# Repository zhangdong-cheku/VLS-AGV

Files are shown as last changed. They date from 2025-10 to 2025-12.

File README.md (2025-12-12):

# VLS-AGV

<p align="center">
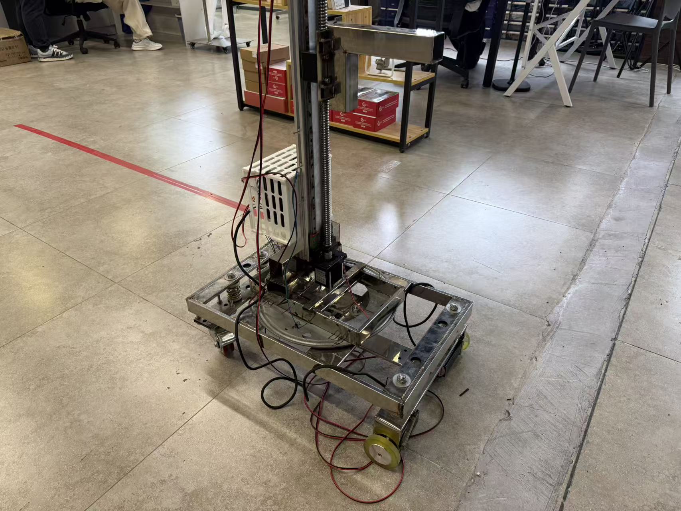
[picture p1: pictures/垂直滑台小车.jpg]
  
  
垂直滑台自主机器人小车 VLS-AGV (Vertical Linear Stage AGV)
针对商用自动导引车(AGV)解决方案成本高的问题，本项目旨在为用户提供一套低成本、可二次开发的开源AGV技术方案。核心亮点是可旋转与可垂直作业组合，支持外接机械臂的开发，在保证性能的同时降低成本，适配中小型仓库物料存取、车间工序转运、实验室样品搬运、零售补货等场景灵活作业。
自主机器人小车由五大核心层级组成：底盘（移动与减震）、底座（承载）、回转支承（左右方向调节）、直线滑动模组（机械臂上下移动调节），机械臂拓展底座（功能延伸接口）。小车的长宽高尺寸为680 mm×412 mm×1121 mm。
其中主动轮为编码器计米轮，由步进电机驱动，从动轮为万向转动轮。底盘与承载底座之间用减震弹簧连接，以提高行驶的稳定性。上部结构和所抓取物体的重量通过空心转盘传递到承载底座。空心转盘由舵机控制，使直线滑动模组能够自由旋转，实现AGV叉车的旋转作业能力。直线滑动模组实现AGV叉车的垂直作业能力。机械臂拓展底座用料为工业铝型材，方便移动组装，此拓展层供用户自主开发，从而满足特定需求。

In response to the problem of high cost of commercial automatic guided vehicle (AGV) solutions, this project aims to provide users with a set of low-cost and redevelopable open-source AGV technical solutions. The core highlight is the combination of rotatable and vertical operation capabilities, supporting the development of external robotic arms. This ensures performance while reducing costs, making it suitable for flexible operations in scenarios such as material storage and retrieval in small and medium-sized warehouses, process transfer in workshops, sample handling in laboratories, and retail replenishment. The autonomous robot trolley is composed of five core levels: the chassis (for movement and shock absorption), the base (for load-bearing), the slewing bearing (for left and right direction adjustment), the linear sliding module (for up and down movement adjustment of the mechanical arm), and the mechanical arm expansion base (for function extension interface). The dimensions of the car's length, width and height are 680 mm×412 mm× 121 mm. Among them, the driving wheel is the encoder metering wheel, driven by a stepping motor, and the driven wheel is a universal rotating wheel. The chassis and the load-bearing base are connected by shock-absorbing springs to enhance the stability during driving. The weight of the superstructure and the grasped object is transferred to the load-bearing base through the hollow turntable. The hollow turntable is controlled by the servo, enabling the linear sliding module to rotate freely and achieving the rotational operation capability of the AGV forklift. The linear sliding module enables the vertical operation capability of AGV forklifts. The material of the mechanical arm expansion base is industrial aluminum profiles, which is convenient for movement and assembly. This expansion layer is available for users to develop independently to meet specific needs.

<p align="center">
  

## 致谢
感谢项目组成员李小峰，田许杰在项目迭代与数据处理中做出的贡献，感谢张东老师在项目方案上的精准指导，也感谢项目组其他成员的通力协作。

## 加入社区

<p align="center">
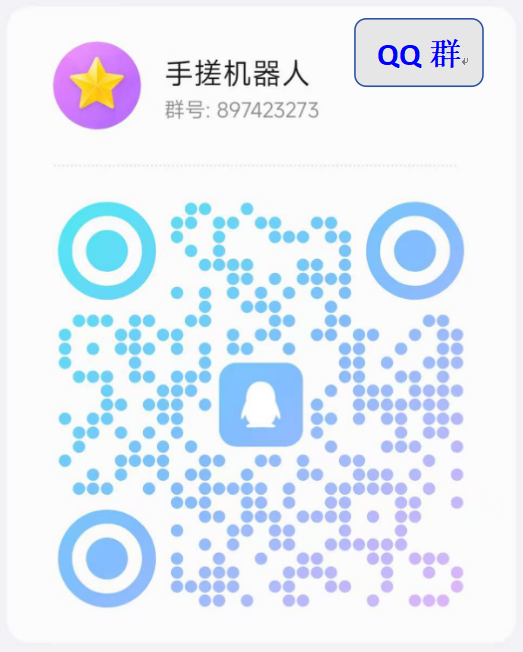
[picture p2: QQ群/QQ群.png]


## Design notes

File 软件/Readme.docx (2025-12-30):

AGV

硬件准备

ESP32S3CAM两个（或者一个ESP32S3CAM和一个ESP32S3）

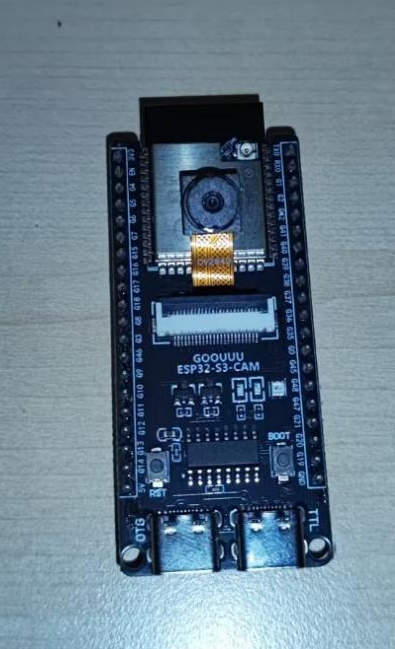
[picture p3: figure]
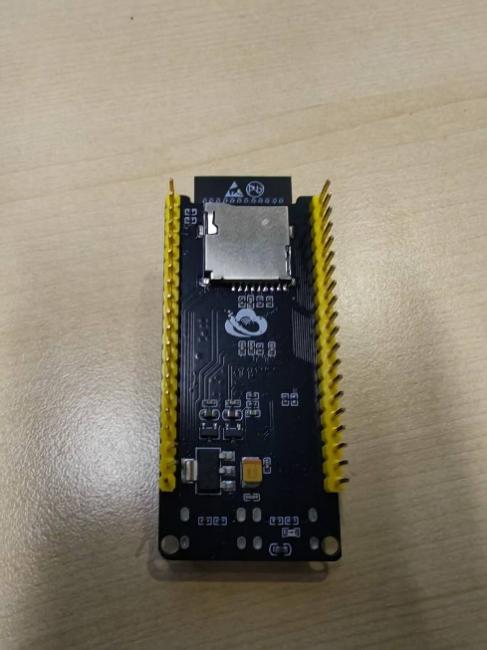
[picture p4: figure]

HDB2305HS50D8步进电机两个

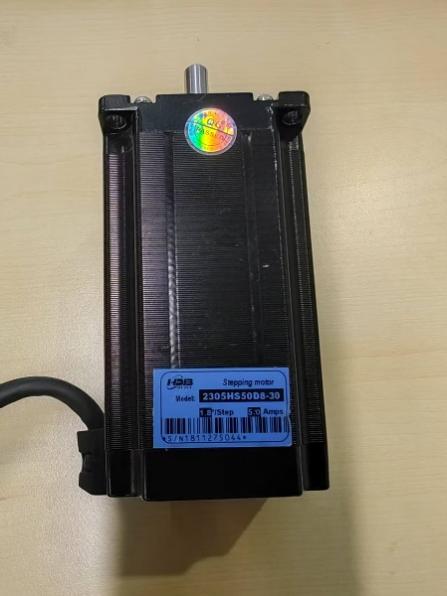
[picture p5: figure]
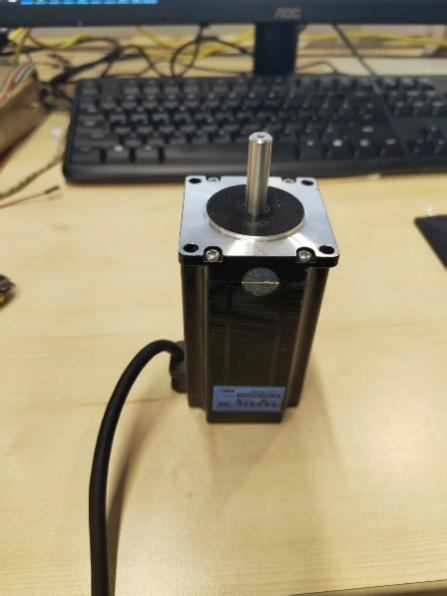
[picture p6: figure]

HDB545E电驱两个

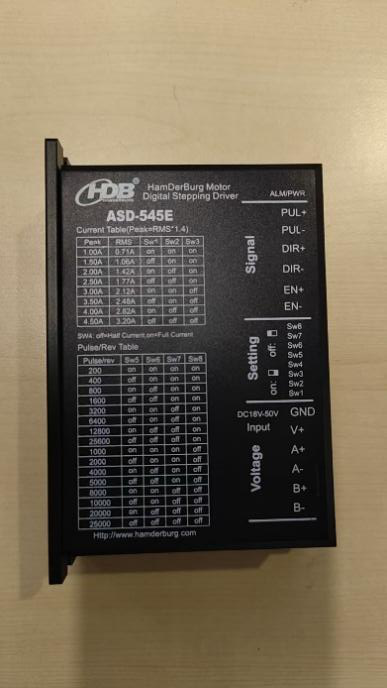
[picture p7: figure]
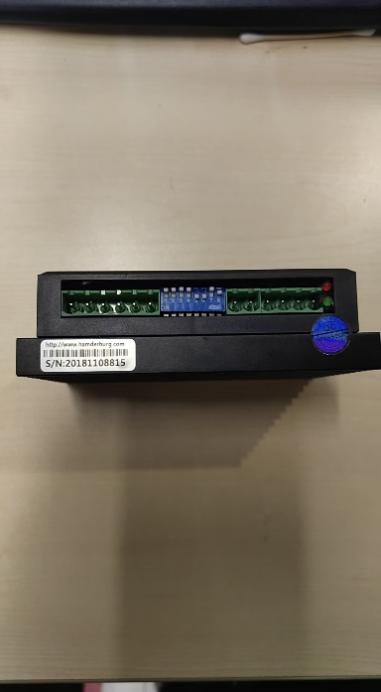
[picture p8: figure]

AGV地盘一个

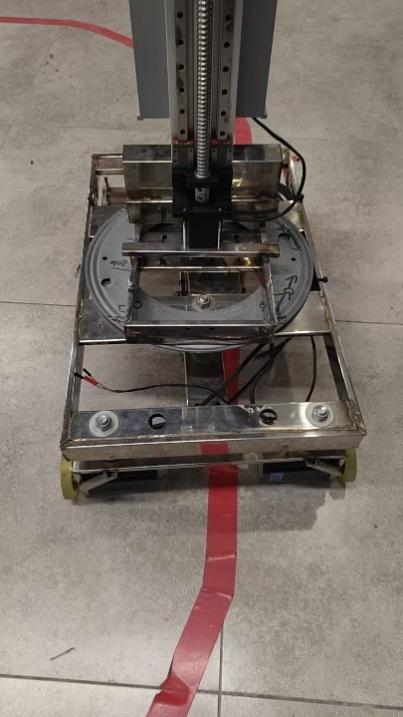
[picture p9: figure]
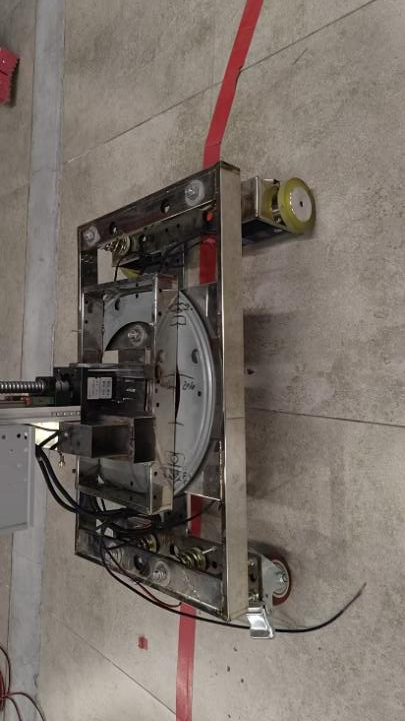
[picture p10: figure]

24V电源一个 电线若干 杜邦线若干

软件部分

软件准备：Arduino IDE

Arduino下载安装：https://wcn5nr4htkrb.feishu.cn/wiki/BrvBwH3u4ibIMBk79PdcOAVOnnb

1.使用Type-C数据线将ESP32S3（注意：这里可以用不带摄像头的，有摄像头的用来采集视频图像）连接到电脑。

2.鼠标移动到WIN图标处，选择设备管理器，如图4所示。

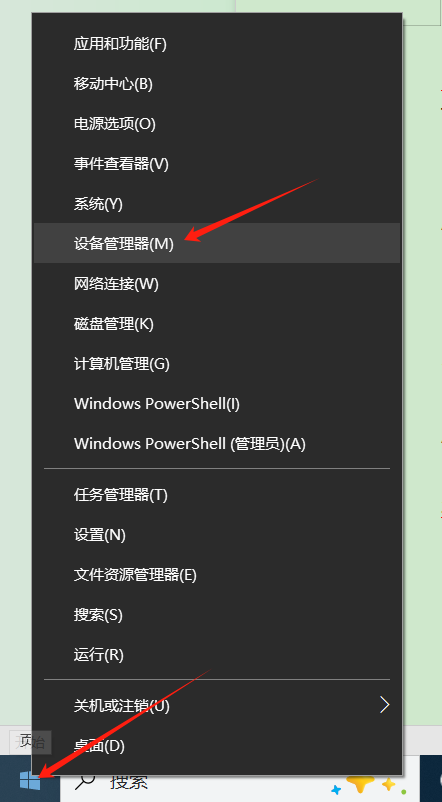
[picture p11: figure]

图4

3.查看在端口中是否出现USB-SERIAL CH340(COMX),记住端口号，CH340驱动可以在https://www.wch.cn/downloads/CH341SER_ZIP.html地址处安装.

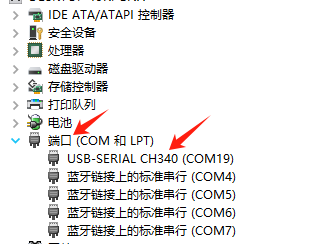
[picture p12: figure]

图5

4. 点击下方文件烧录程序

打开方式选择Arduino IDE，

点击ArduinoIDE上侧工具栏，选择端口，

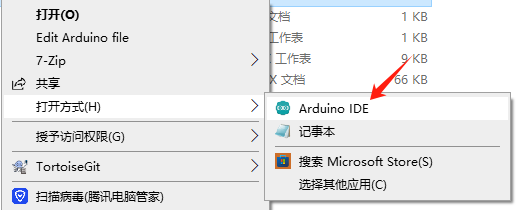
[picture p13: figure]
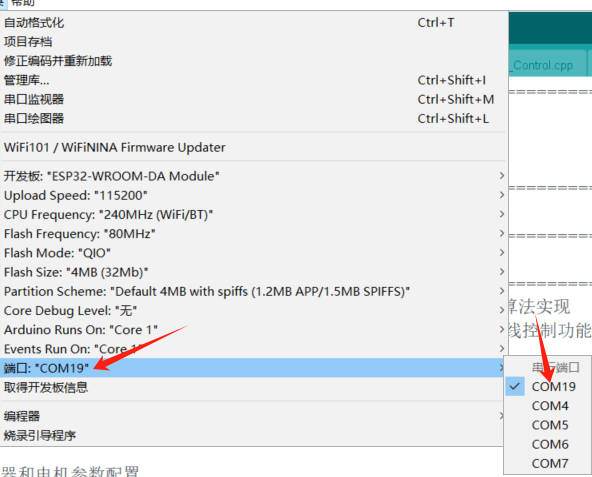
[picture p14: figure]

点击ArduinoIDE页面左上角的编译(时间较长，耐心等待)，编译通过后点击上传(时间较长，耐心等待)，
烧录完毕
至此完成第一个ESP32S3的烧录

用同样的步骤将下面的程序烧录到带有摄像头的ESP32S3CAM

烧录成功后再Arduino的串口监视器会有下面的提示

将上面的IP地址复制到浏览器中可以看到实时的视频画面

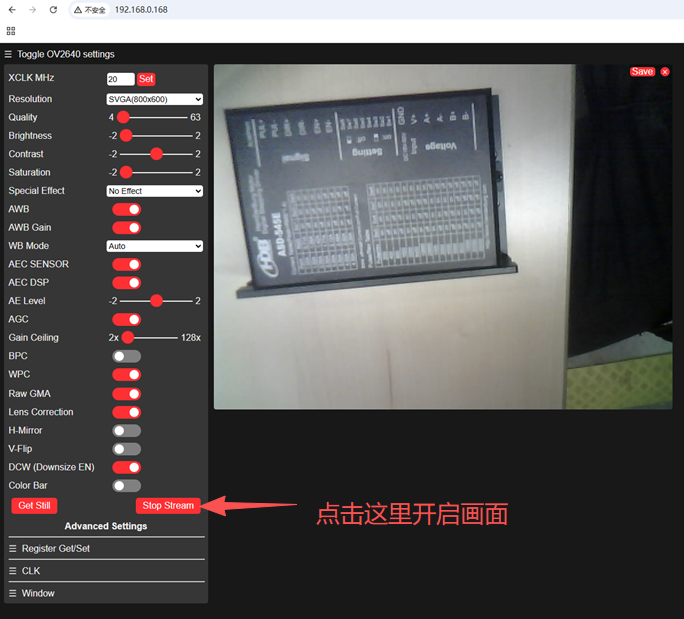
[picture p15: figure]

开始运行

首先在TRAE中打开文件运行

文件

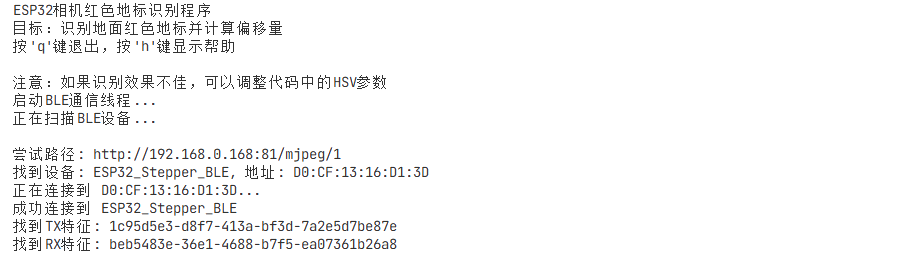
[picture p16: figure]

提示成功连接到蓝牙设备证明连接成功

连接成功后AGV自动运行

运行逻辑是下面代码中的逻辑
偏离度offset

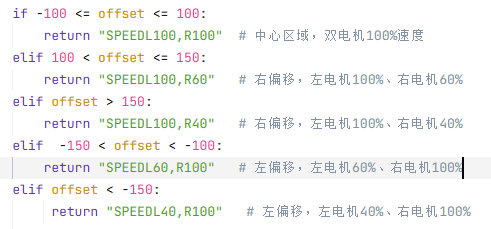
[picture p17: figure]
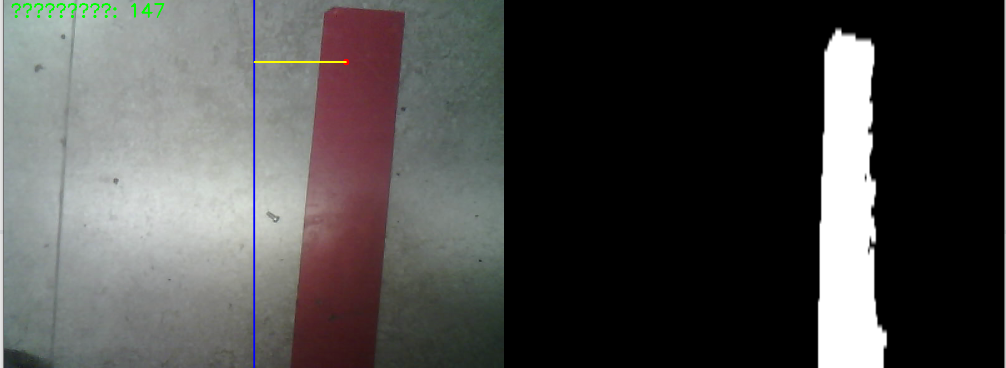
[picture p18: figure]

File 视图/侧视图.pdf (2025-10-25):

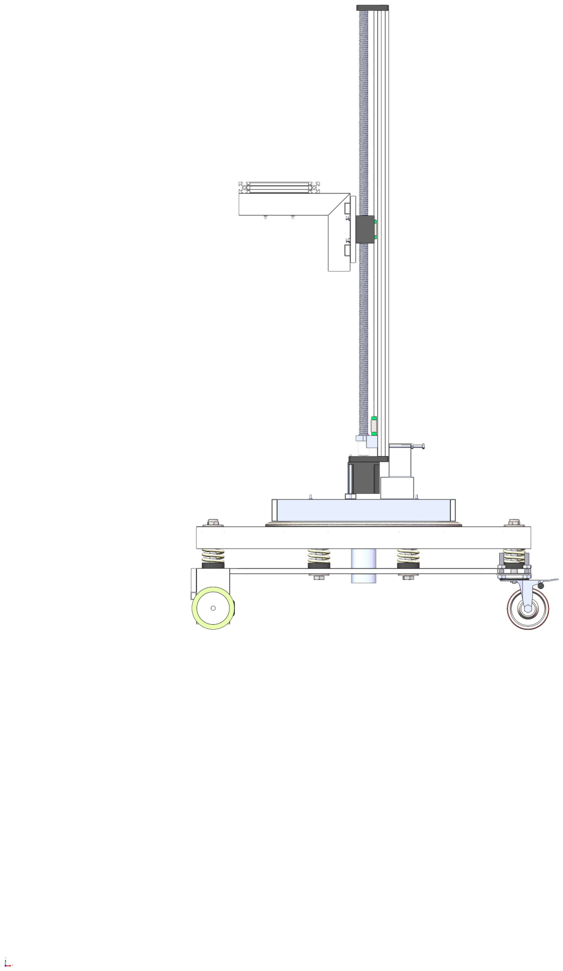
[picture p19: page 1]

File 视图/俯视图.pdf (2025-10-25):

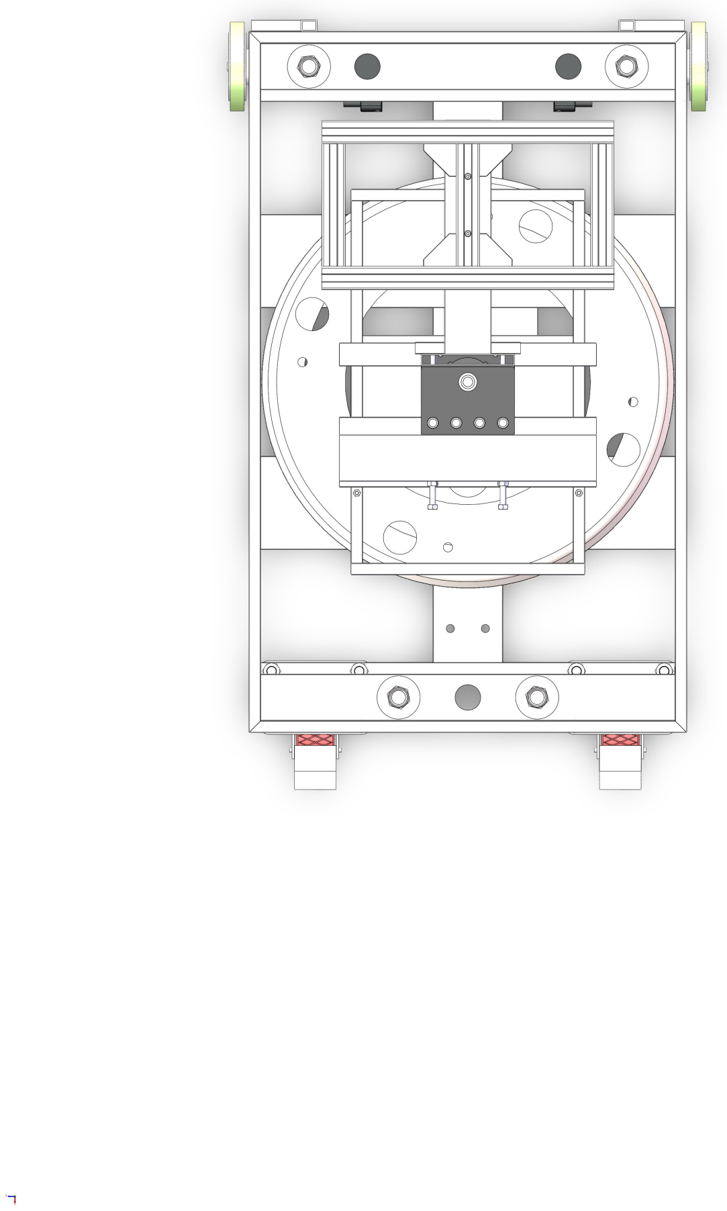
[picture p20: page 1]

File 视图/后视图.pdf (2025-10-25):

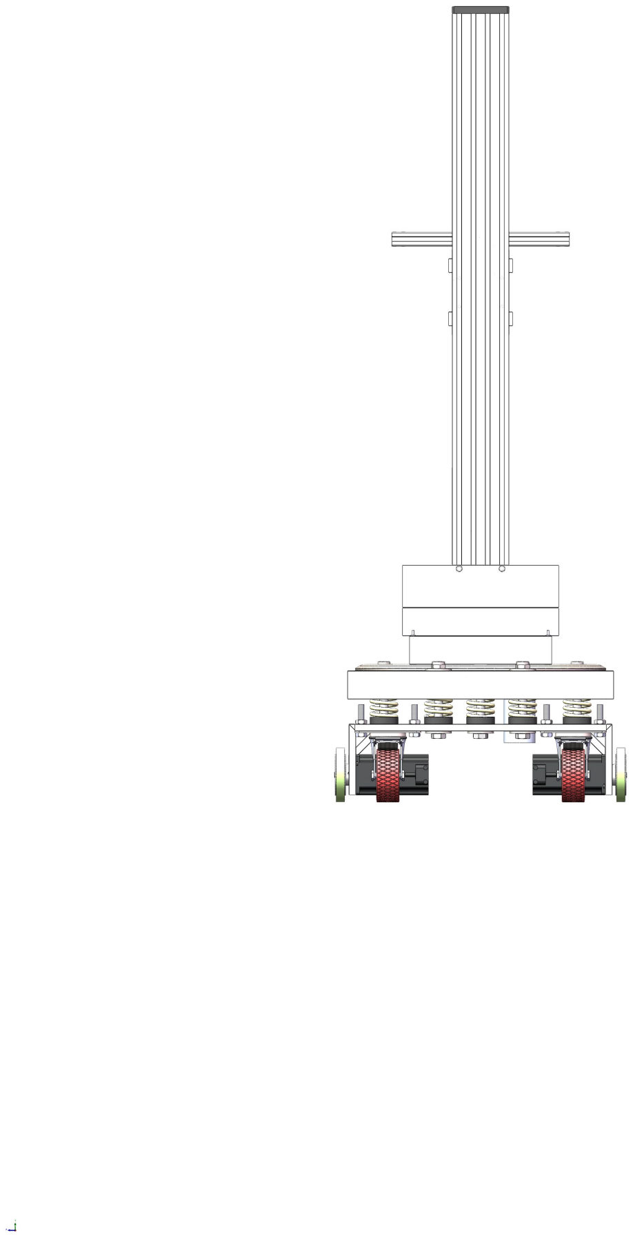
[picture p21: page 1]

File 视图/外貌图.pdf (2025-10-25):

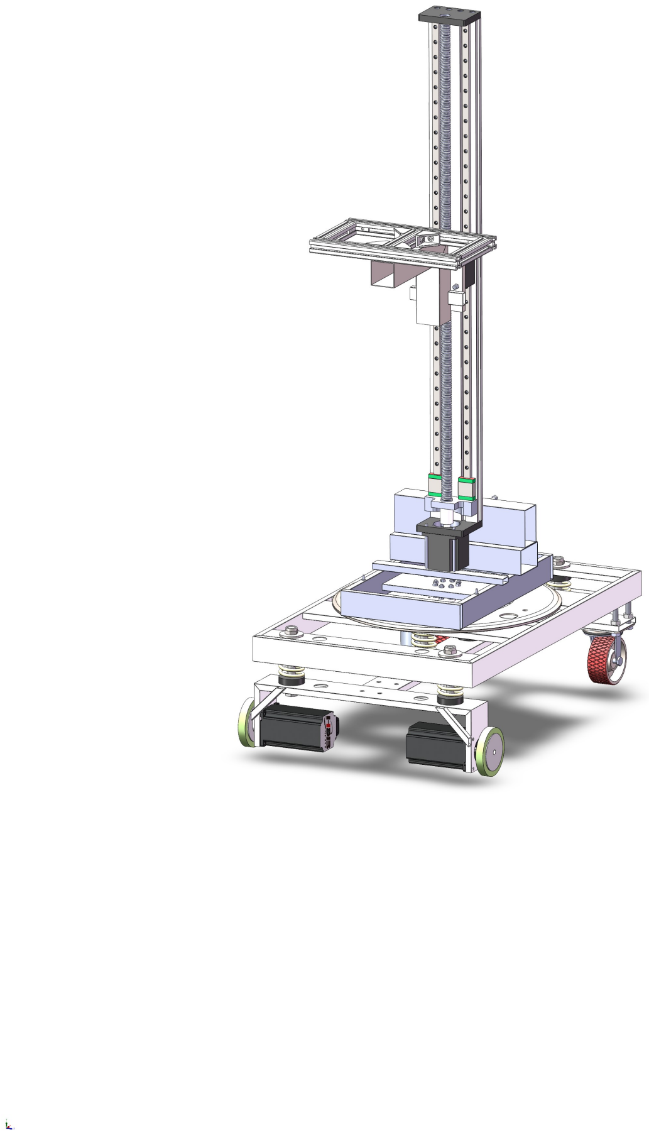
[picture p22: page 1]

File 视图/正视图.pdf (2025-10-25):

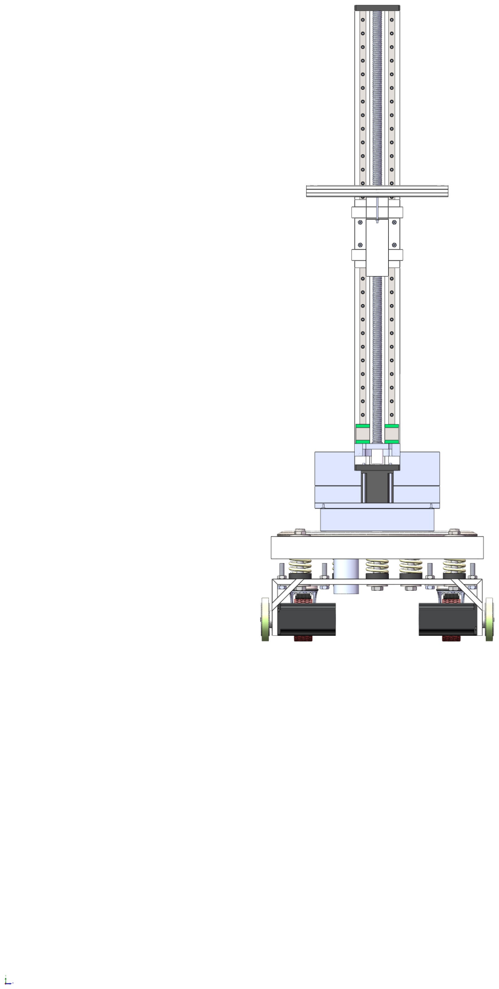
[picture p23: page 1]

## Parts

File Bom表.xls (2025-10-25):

序号 | 零件 | 数量 | 规格 | 参考总价/CNY | 备注 | 网购链接1 | 网购链接2
1 | 编码器包胶计米轮 | 2个 | 直径80 mm(周长250 mm)孔8 mm | 52~64 | 主动轮 | https://item.taobao.com/item.htm?ali_trackid=1_81e027c8503457fb4891e9123a107a4b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 | https://detail.1688.com/offer/597682419555.html?offerId=597682419555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
2 | 步进电机 | 2个 | 汉德保2305HS50D8-30 | 480~720 | 控制主动轮 | https://item.taobao.com/item.htm?id=573731717226 | https://item.taobao.com/item.htm?id=718525628843
3 | 万向轮 | 2个 | 3寸刹车橡胶轮 | 12.48~15 | 从动轮 | https://detail.1688.com/offer/535911071862.html?spm=a261y.25179003.recommendOffer.3.227e38ecRRlY1W | https://detail.1688.com/offer/780807622032.html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
4 | 减震弹簧 | 6个 | 吊机簧双簧加粗 | 34.17~37.22 | 减震 | https://mobile.yangkeduo.com/goods1.html?ps=bEbyI2X8ZD | https://mobile.yangkeduo.com/goods.html?ps=f2iqdHUg1H
5 | 260 Kg大扭矩舵机 | 1套 | 775电机 电路板 法兰 | 268~301 | 控制转盘 | https://mobile.yangkeduo.com/mall_page.html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 | https://item.taobao.com/item.htm?ali_trackid=1_b094263d5058f184142d6f5f5eba9514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
6 | 空心转盘 | 1个 | 14寸镀锌外径350 mm | 10.5~13 | 旋转作业 | https://detail.1688.com/offer/923778899375.html?offerId=923778899375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 | https://detail.1688.com/offer/584002091954.html?spm=a26352.b28411319.offerlist.403.74fa1e628fbwMB
7 | 直线滑动模组 | 1套 | GX80双导轨 滚珠丝杆（有效行程700 mm） 57电机 | 352~388 | 控制机械臂 | https://mobile.yangkeduo.com/goods1.html?ps=7aPjmQHQNJ | https://item.taobao.com/item.htm?ali_trackid=282_aad009b9b815aa369570dda5f23b63c6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
8 | 螺栓螺母副 | 12套 | M5×20 mm | 500 | 固定步进电机及空心转盘 | 委托工厂制作 | 委托工厂制作
 |  | 8套 | M8×40 mm |  | 固定从动轮
 |  | 4套 | M3×15 mm螺钉 |  | 固定舵机
 |  | 8套 | M4×20 mm |  | 固定法兰
 |  | 4套 | M3×50 mm |  | 固定直线模组底座
 |  | 2套 | M4×80 mm |  | 固定直线模组电机
 |  | 2套 | M5×60 mm |  | 固定直线模组铝型材
 |  | 4套 | M4×20 mm |  | 固定滑块
 |  | 2套 | M3×60 mm |  | 固定机械臂拓展底座
9 | 不锈钢圆角矩形管 | 1405 mm | 10 mm×60 mm×1 mm |  | 底盘用料
 |  | 160 mm | 10 mm×10 mm×1 mm
 |  | 2660 mm | 10 mm×40 mm×1 mm |  | 底座用料
 |  | 837 mm | 10 mm×80 mm×1 mm
 |  | 1020 mm | 10 mm×40 mm×1 mm |  | 直线模组底座用料
 |  | 180 mm | 10 mm×80 mm×1 mm
 |  | 220 mm | 10 mm×20 mm×1 mm
 |  | 440 | 40 mm×60 mm×1 mm
 |  | 120 mm | 10 mm×80 mm×1 mm |  | 机械臂拓展底座用料
 |  | 180 mm | 10 mm×20 mm×1 mm
 |  | 340 mm | 40 mm×40 mm×1 mm
10 | 工业铝型材 | 815 mm | 欧标2020
11 | 铝型材连接件 | 4个 | 2028角码套装
 |  | 4个 | 2020槽内连接件套装

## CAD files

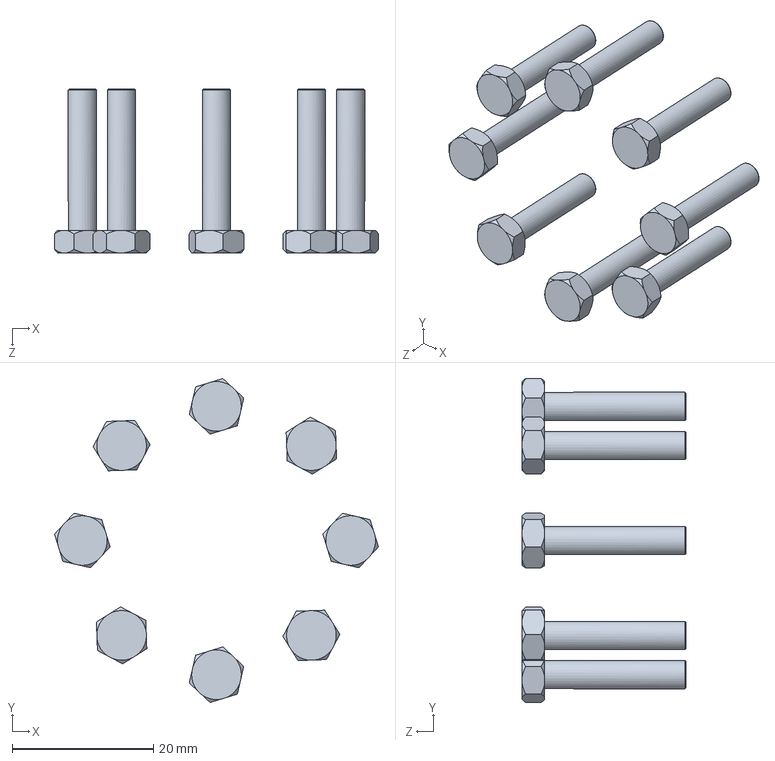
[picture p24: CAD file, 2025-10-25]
三维模型/舵机/带螺栓舵盘.SLDASM
45.9 x 45.9 x 23.2 mm
M4×20螺栓 x 8

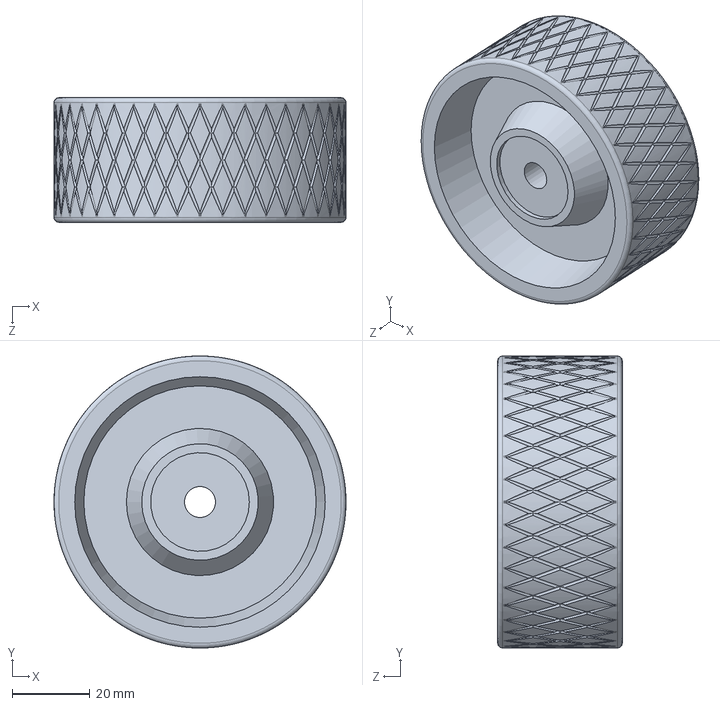
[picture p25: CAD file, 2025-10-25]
三维模型/万向轮/轮胎.SLDPRT
75.0 x 75.0 x 32.0 mm

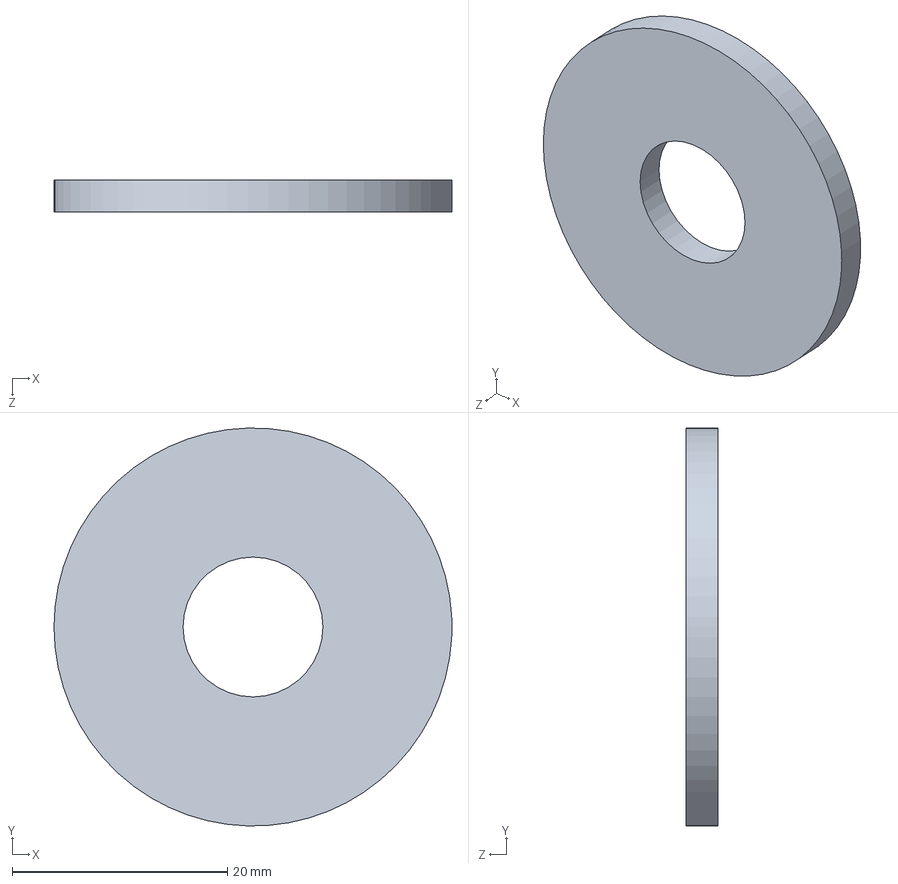
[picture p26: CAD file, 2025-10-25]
三维模型/减震/GB╱T 96.1-2002[大垫圈 A级12 C1].sldprt
37.0 x 37.0 x 3.00 mm

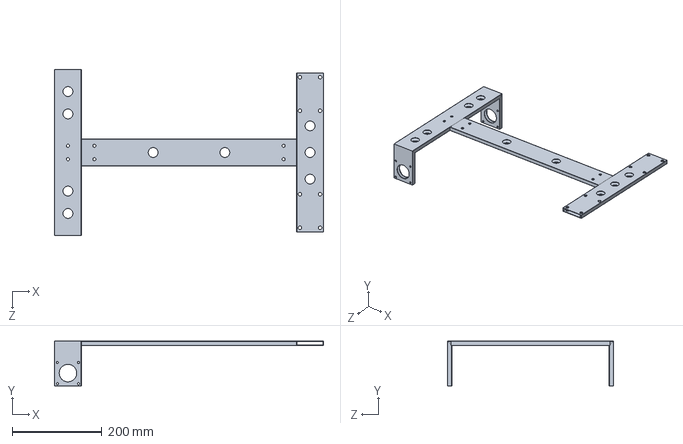
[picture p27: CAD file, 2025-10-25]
三维模型/底盘与底座/底盘.SLDPRT
600.0 x 100.0 x 370.8 mm

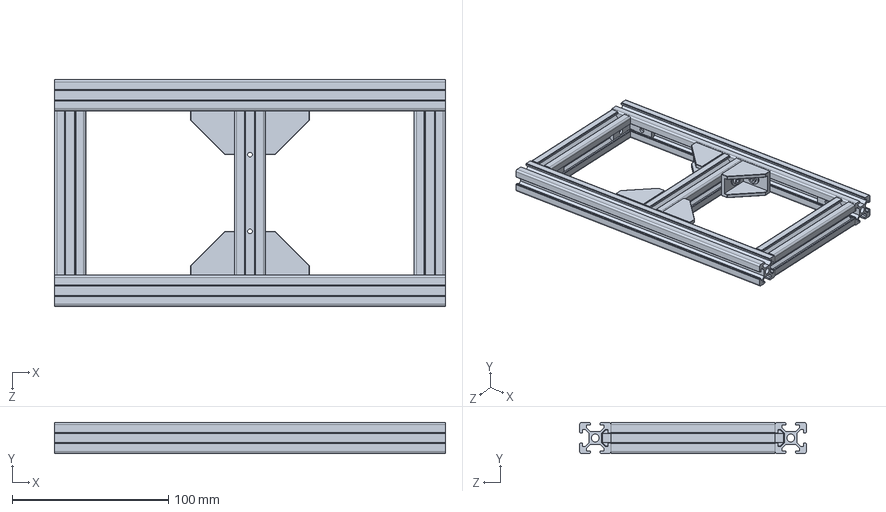
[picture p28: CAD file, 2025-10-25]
三维模型/机械拓展层/2020工业铝型材拼接件.SLDPRT
250.0 x 20.0 x 145.0 mm

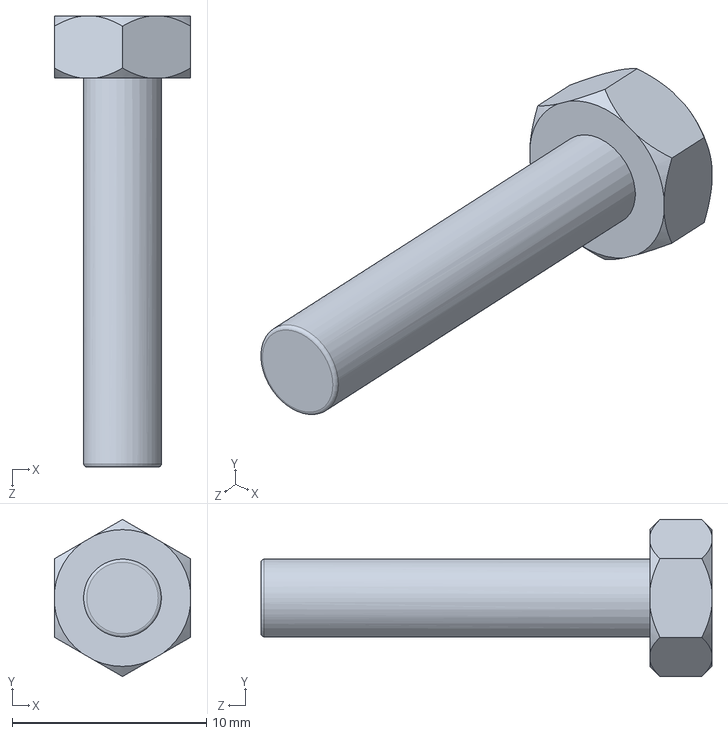
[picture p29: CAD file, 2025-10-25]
三维模型/舵机/M4×20螺栓.SLDPRT
7.00 x 8.08 x 23.2 mm

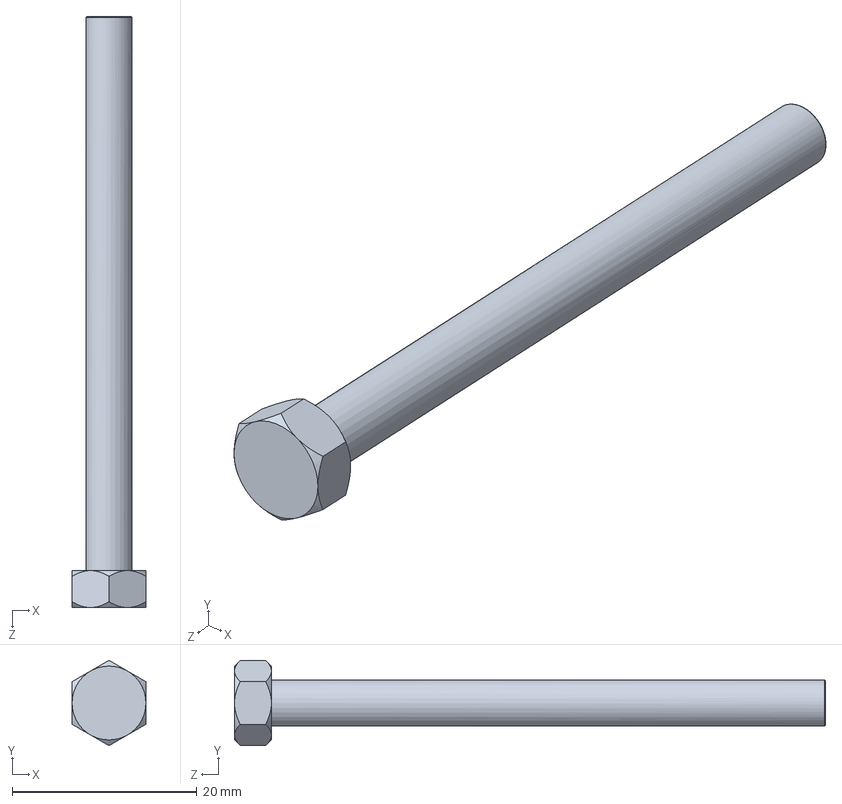
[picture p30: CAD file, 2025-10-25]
三维模型/转盘/M5×60螺柱.SLDPRT
8.00 x 9.24 x 64.0 mm

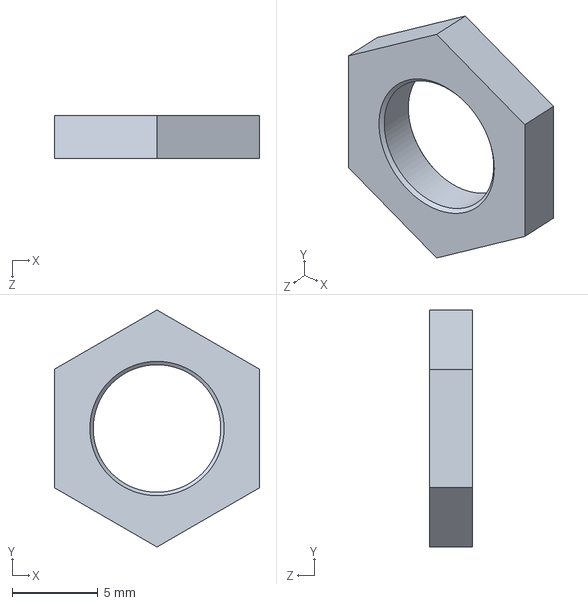
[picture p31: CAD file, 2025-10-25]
三维模型/万向轮/螺母.SLDPRT
12.0 x 13.9 x 2.50 mm

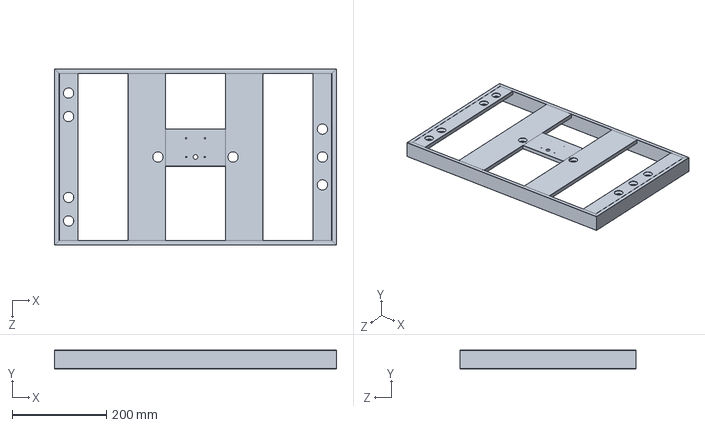
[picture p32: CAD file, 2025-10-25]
三维模型/底盘与底座/底座.SLDPRT
600.0 x 40.0 x 374.6 mm

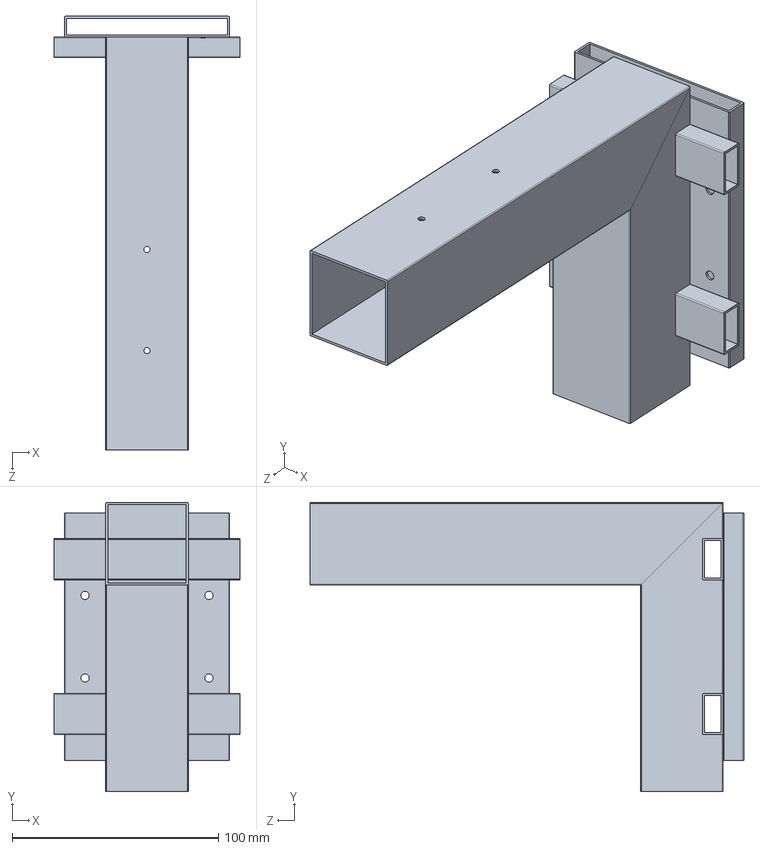
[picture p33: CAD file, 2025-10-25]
三维模型/机械拓展层/拓展层底座.SLDPRT
90.0 x 140.0 x 210.0 mm

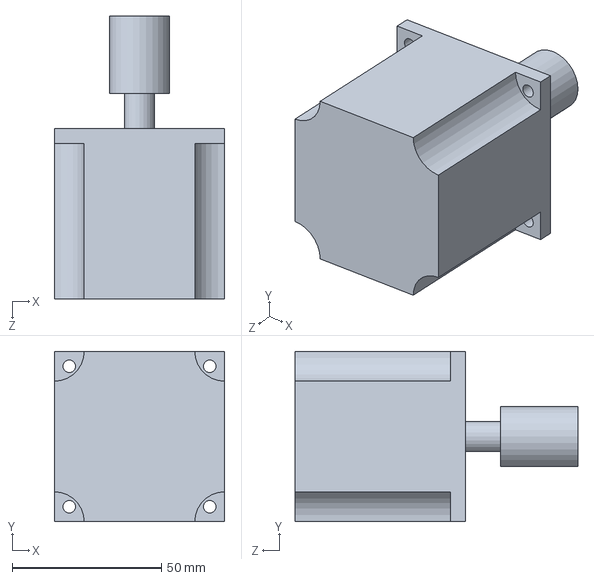
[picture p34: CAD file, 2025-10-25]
三维模型/直线模组/57驱动电机.SLDPRT
57.0 x 57.0 x 94.7 mm

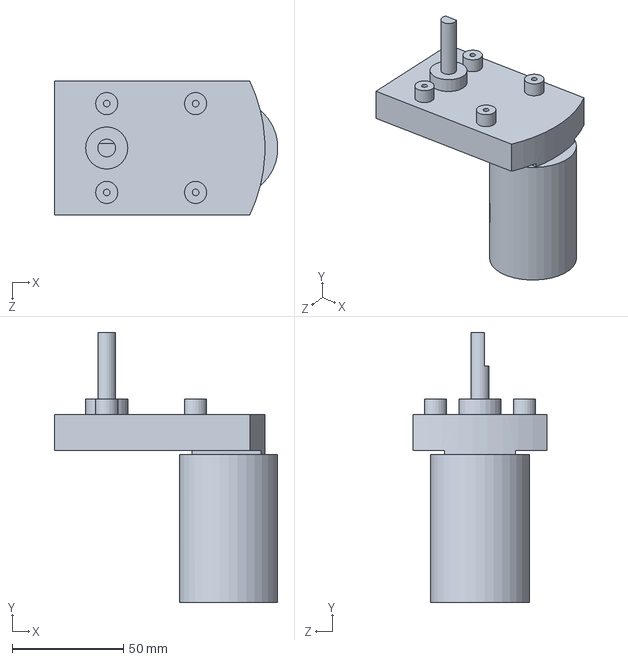
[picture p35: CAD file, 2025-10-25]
三维模型/舵机/大扭矩舵机.SLDPRT
100.6 x 121.5 x 60.2 mm

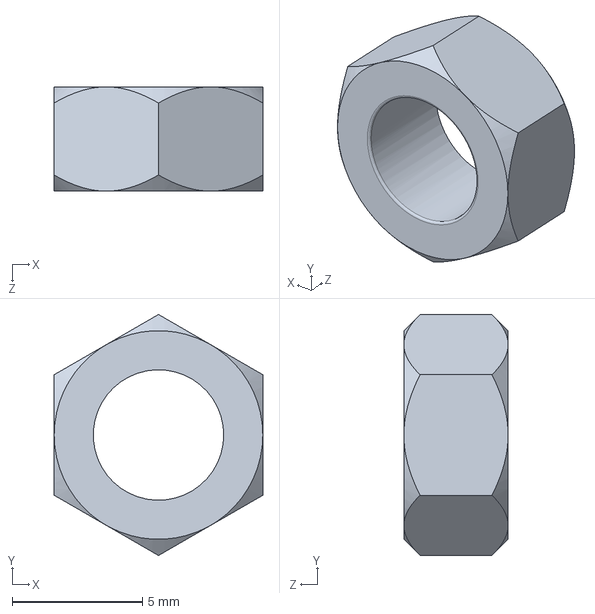
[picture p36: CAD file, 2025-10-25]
三维模型/转盘/M5螺母.SLDPRT
8.00 x 9.24 x 4.00 mm

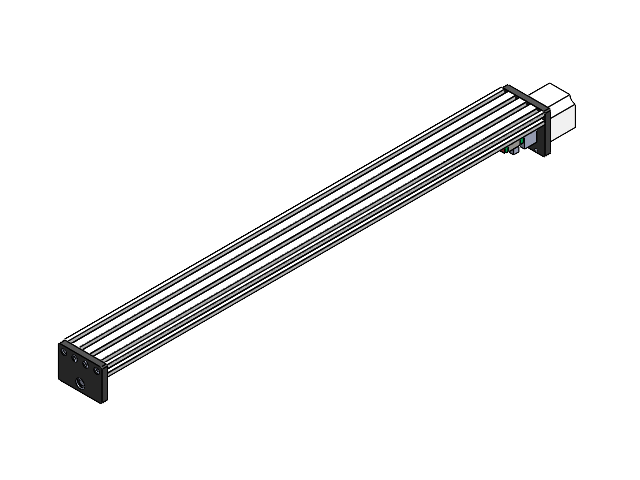
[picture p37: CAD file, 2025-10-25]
三维模型/直线模组/直线滑动模组.SLDASM
滚珠丝杆
57驱动电机

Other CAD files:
三维模型/减震/减振.SLDASM
三维模型/机械拓展层/机械拓展层.SLDASM
三维模型/转盘/直线模组底座.SLDASM
三维模型/万向轮/万向轮.SLDASM
三维模型/万向轮/M8×40螺栓.SLDPRT
三维模型/万向轮/M8螺母.SLDPRT
三维模型/万向轮/安装板.SLDPRT
三维模型/万向轮/车轮固定螺母.SLDPRT
三维模型/万向轮/车轮盖.SLDPRT
三维模型/万向轮/车轮螺栓.SLDPRT
三维模型/减震/GB╱T 5782-2016[六角头螺栓M12×100].sldprt
三维模型/减震/GB╱T 6172.2-2016[非金属嵌件六角锁紧薄螺母M12].sldprt
三维模型/减震/弹簧.SLDPRT
三维模型/减震/胶垫.SLDPRT
三维模型/底盘与底座/57CM30.SLDPRT
三维模型/底盘与底座/斜撑.SLDPRT
三维模型/底盘与底座/编码器计米轮.SLDPRT
三维模型/机械拓展层/M3×60平圆头内六角螺栓.SLDPRT
三维模型/机械拓展层/M4×20平头十字螺钉.SLDPRT
三维模型/机械拓展层/直线模组滑块.SLDPRT
三维模型/舵机/M4螺母.SLDPRT
三维模型/舵机/舵盘.SLDPRT
三维模型/转盘/M3×50平圆头内六角螺栓.SLDPRT
三维模型/转盘/M3螺母.SLDPRT
三维模型/转盘/M4×80螺柱.SLDPRT
三维模型/转盘/框.SLDPRT
三维模型/转盘/转盘.SLDPRT

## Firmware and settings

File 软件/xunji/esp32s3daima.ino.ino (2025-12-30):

/*
ESP32S3 双步进电机独立控制程序（蓝牙版）
支持一条命令独立设置两个电机的方向、转速和步数
*/

// 引入BLE库
#include <BLEDevice.h>
#include <BLEServer.h>
#include <BLEUtils.h>
#include <BLE2902.h>

// BLE服务和特征UUID
#define SERVICE_UUID        "4fafc201-1fb5-459e-8fcc-c5c9c331914b"
#define RX_CHARACTERISTIC_UUID "beb5483e-36e1-4688-b7f5-ea07361b26a8"  // 接收数据
#define TX_CHARACTERISTIC_UUID "1c95d5e3-d8f7-413a-bf3d-7a2e5d7be87e"  // 发送数据

// BLE对象
BLEServer* pServer = NULL;
BLECharacteristic* pTxCharacteristic = NULL;
BLECharacteristic* pRxCharacteristic = NULL;
bool deviceConnected = false;
bool oldDeviceConnected = false;

// BLE接收缓冲区（环形缓冲区，避免String操作的并发问题）

/*
什么是环形缓冲区？
环形缓冲区（也叫循环缓冲区）是一种 固定大小的、首尾相连的数据结构 ，专门用于 生产者-消费者模型 的数据传输。可以想象成：
数据写入（BLE回调函数 - 当蓝牙接收到数据时， 生产者（BLE回调函数） 会将数据写入缓冲区的 写入位置（bleBufferHead） ，并 移动写入位置 到下一个空位置。
数据读取（主循环 - 第185-189行）
主循环中， 消费者（readByte函数） 


- 一个 首尾相接的环形传送带 （固定长度）
- 一边有人 放东西 （生产者），一边有人 取东西 （消费者）
- 当传送带满了，新东西要么 替换旧东西 ，要么 停止放入
- 当传送带空了，就 没有东西可拿

第27行： volatile int bleBufferHead = 0;  // 写入位置（BLE回调写入）
- volatile ： 易变关键字 ，告诉编译器"这个变量随时可能被硬件或其他代码修改，不要优化它"
- int ：整数类型（4字节）
- bleBufferHead ：变量名，意为"BLE缓冲区的头部"，表示 新数据写入的位置
- = 0 ：初始值为0，从缓冲区的第一个位置开始写入
- 注释 ：这个位置由BLE回调函数（蓝牙数据到达时的处理函数）来更新 第28行： volatile int bleBufferTail = 0;  // 读取位置（主循环读取）
- bleBufferTail ：变量名，意为"BLE缓冲区的尾部"，表示 旧数据读取的位置
- = 0 ：初始值为0，从缓冲区的第一个位置开始读取
- 注释 ：这个位置由主循环（loop()函数）来更新 二、上下文：环形缓冲区的工作原理
这两个变量配合第26行的 char bleBuffer[BLE_BUFFER_SIZE]; ，组成了一个 环形缓冲区 （也叫循环缓冲区）：
把BLE缓冲区比作一个 快递中转站 ：

- bleBuffer ：中转站的 货仓 （容量256个包裹）
- bleBufferHead ：快递 入库口 的位置标记（新快递放这里）
- bleBufferTail ：快递 出库口 的位置标记（旧快递从这里取走）
- volatile ：因为入库和出库是 两个人同时操作 ，所以位置标记可能随时变化
实际工作流程 1. 数据写入（BLE回调）： 蓝牙接收到数据时，BLE回调函数将数据写入bleBuffer[bleBufferHead] 然后bleBufferHead向后移动一位（到下一个写入位置） 
如果到达缓冲区末尾（255），就回到开头（0），形成"环形"   2. 数据读取（主循环）： 主循环从bleBuffer[bleBufferTail]读取数据 然后bleBufferTail向后移动一位（到下一个读取位置） 
同样，如果到达末尾就回到开头   3. 空/满判断： 当head == tail时：缓冲区为空（没有新数据） 当(head + 1) % BLE_BUFFER_SIZE == tail时：缓冲区已满（不能再写入）*/
#define BLE_BUFFER_SIZE 256
char bleBuffer[BLE_BUFFER_SIZE];
volatile int bleBufferHead = 0;  // 写入位置（BLE回调写入）bleBufferHead：变量名，意为"BLE缓冲区的头部"，表示新数据写入的位置
volatile int bleBufferTail = 0;  // 读取位置（主循环读取）bleBufferTail ：变量名，意为"BLE缓冲区的尾部"，表示 旧数据读取的位置

// BLE设备名称
#define BLE_DEVICE_NAME "ESP32_Stepper_BLE"

// 电机引脚定义
#define R_STEP_PIN 4    // 右电机步进脉冲引脚
#define R_DIR_PIN 5     // 右电机方向控制引脚
#define R_ENABLE_PIN 6  // 右电机使能引脚（低电平使能）
#define L_STEP_PIN 12   // 左电机步进脉冲引脚
#define L_DIR_PIN 19    // 左电机方向控制引脚
#define L_ENABLE_PIN 14 // 左电机使能引脚（低电平使能）

// 步进延迟时间（微秒），控制电机速度
#define STEP_DELAY 100

// 电机方向设置
#define R_FORWARD LOW  // 右电机正转方向
#define R_BACKWARD HIGH  // 右电机反转方向
#define L_FORWARD HIGH   // 左电机正转方向
#define L_BACKWARD LOW // 左电机反转方向

// 电机状态结构体
typedef struct {
  boolean isRunning;    // 电机运行状态
  byte direction;       // 当前方向
  int remainingSteps;   // 剩余步数
  unsigned long lastStepTime; // 上一步时间
  int stepPin;          // 步进引脚
  int dirPin;           // 方向引脚
  boolean stepState;    // 当前步进引脚状态（HIGH/LOW）
  boolean isContinuousRunning; // 持续运行模式标志
  unsigned long stepDelay; // 步进延迟时间（微秒），控制电机速度
} MotorState;

// 初始化左右电机状态
MotorState rightMotor = {false, R_FORWARD, 0, 0, R_STEP_PIN, R_DIR_PIN, LOW, false, STEP_DELAY};
MotorState leftMotor = {false, L_FORWARD, 0, 0, L_STEP_PIN, L_DIR_PIN, LOW, false, STEP_DELAY};

// 命令缓冲区
String receivedCommand = "";
String lastProcessedCommand = "";  // 记录最后处理的命令，防止重复执行
unsigned long lastCommandTime = 0; // 最后命令时间
#define COMMAND_DEBOUNCE_MS 100    // 命令去重时间窗口（毫秒）

// 调试模式开关（设为true可以看到详细的接收数据）
#define DEBUG_MODE false

// BLE服务器回调类
class MyServerCallbacks: public BLEServerCallbacks {
    void onConnect(BLEServer* pServer) {
      deviceConnected = true;
      #if DEBUG_MODE
      Serial.println("BLE客户端已连接");
      #endif
    };

    void onDisconnect(BLEServer* pServer) {
      deviceConnected = false;
      #if DEBUG_MODE
      Serial.println("BLE客户端已断开");
      #endif
    }
};

// BLE接收特征回调类
class MyCallbacks: public BLECharacteristicCallbacks {
    void onWrite(BLECharacteristic *pCharacteristic) {
      String value = pCharacteristic->getValue().c_str();
      if (value.length() > 0) {
        #if DEBUG_MODE
        // 调试：显示原始接收数据
        Serial.print("[BLE接收] 长度:");
        Serial.print(value.length());
        Serial.print(" 内容:'");
        Serial.print(value);
        Serial.print("' HEX:");
        for (size_t i = 0; i < value.length(); i++) {
          Serial.print(" 0x");
          Serial.print((byte)value[i], HEX);
        }
        Serial.println();
        #endif
        
        // 将接收到的数据写入环形缓冲区
        for (size_t i = 0; i < value.length(); i++) {
          int nextHead = (bleBufferHead + 1) % BLE_BUFFER_SIZE;
          
          // 检查缓冲区是否已满
          if (nextHead != bleBufferTail) {
            bleBuffer[bleBufferHead] = value[i];
            bleBufferHead = nextHead;
          } else {
            #if DEBUG_MODE
            Serial.println("[警告] BLE缓冲区已满，丢弃数据！");
            #endif
            break;
          }
        }
        
        #if DEBUG_MODE
        // 计算缓冲区中的数据量
        int bufferSize = (bleBufferHead - bleBufferTail + BLE_BUFFER_SIZE) % BLE_BUFFER_SIZE;
        Serial.print("[缓冲区] 当前数据量:");
        Serial.print(bufferSize);
        Serial.println(" 字节");
        #endif
      }
    }
};

// BLE辅助函数：同时向串口和BLE发送消息
// 添加一个简单的串口输出检查，避免在无串口连接时阻塞
void printToBoth(String message) {
  // 仅在DEBUG_MODE下且有数据发送可能时才输出到串口
  // 避免无串口连接时的阻塞
  #if DEBUG_MODE
  Serial.println(message);
  #endif
  if (deviceConnected && pTxCharacteristic != NULL) {
    String msg = message + "\n";
    pTxCharacteristic->setValue(msg);
    pTxCharacteristic->notify();
  }
}

void printToBoth(const char* message) {
  // 仅在DEBUG_MODE下且有数据发送可能时才输出到串口
  // 避免无串口连接时的阻塞
  #if DEBUG_MODE
  Serial.println(message);
  #endif
  if (deviceConnected && pTxCharacteristic != NULL) {
    String msg = String(message) + "\n";
    pTxCharacteristic->setValue(msg);
    pTxCharacteristic->notify();
  }
}

// 检查是否有可用数据（串口或BLE）
int availableData() {
  if (Serial.available() > 0) return 1;  // 串口数据
  if (bleBufferTail != bleBufferHead) return 2;  // BLE数据
  return 0; // 无数据
}

// 从可用源读取一个字节
char readByte() {
  if (Serial.available() > 0) {
    return Serial.read();
  }
  // 从环形缓冲区读取
  if (bleBufferTail != bleBufferHead) {
    char c = bleBuffer[bleBufferTail];
    bleBufferTail = (bleBufferTail + 1) % BLE_BUFFER_SIZE;
    return c;
  }
  return 0;
}

// 电机单步控制函数 - 完全非阻塞式（状态机方式）
void updateMotor(MotorState &motor) {
  // 运行条件：电机正在运行且（有剩余步数 或 处于持续运行模式）
  if (!motor.isRunning || (!motor.isContinuousRunning && motor.remainingSteps <= 0)) {
    return;
  }
  
  unsigned long currentTime = micros();
  
  // 状态机：HIGH 和 LOW 状态交替
  if (motor.stepState == LOW) {
    // 当前是LOW状态，检查是否该切换到HIGH
    if (currentTime - motor.lastStepTime >= motor.stepDelay) {
      digitalWrite(motor.stepPin, HIGH);
      motor.stepState = HIGH;
      motor.lastStepTime = currentTime;
    }
  } else {
    // 当前是HIGH状态，检查是否该切换到LOW（完成一步）
    if (currentTime - motor.lastStepTime >= motor.stepDelay) {
      digitalWrite(motor.stepPin, LOW);
      motor.stepState = LOW;
      motor.lastStepTime = currentTime;
      
      // 非持续运行模式下才更新剩余步数和检查完成
      if (!motor.isContinuousRunning) {
        motor.remainingSteps--;  // 完成一步
        
        // 检查是否完成所有步数
        if (motor.remainingSteps <= 0) {
          motor.isRunning = false;
          String msg = String(motor.stepPin == R_STEP_PIN ? "右" : "左") + "电机运动完成";
          printToBoth(msg);
        }
      }
    }
  }
}

// 显示帮助信息
void showHelp() {
  printToBoth("========================================");
  printToBoth("ESP32 双步进电机独立控制系统");
  printToBoth("========================================");
  printToBoth("");
  printToBoth("【主要功能】");
  printToBoth("一条命令独立控制两个电机的方向和步数");
  printToBoth("");
  printToBoth("【命令格式】");
  printToBoth("BOTH<右方向><右步数>,<左方向><左步数>");
  printToBoth("");
  printToBoth("【参数说明】");
  printToBoth("- 方向: F=正转, B=反转");
  printToBoth("- 步数: 任意正整数");
  printToBoth("- 必须用逗号分隔左右电机参数");
  printToBoth("");
  printToBoth("【命令示例】");
  printToBoth("BOTHF500,B1000  - 右电机正转500步, 左电机反转1000步");
  printToBoth("BOTHB800,F600   - 右电机反转800步, 左电机正转600步");
  printToBoth("BOTHF1000,F500  - 右电机正转1000步, 左电机正转500步");
  printToBoth("BOTHB300,B800   - 右电机反转300步, 左电机反转800步");
  printToBoth("");
  printToBoth("【单个电机控制】");
  printToBoth("RF500   - 右电机正转500步");
  printToBoth("RB1000  - 右电机反转1000步");
  printToBoth("LF500   - 左电机正转500步");
  printToBoth("LB1000  - 左电机反转1000步");
  printToBoth("");
  printToBoth("【其他命令】");
  printToBoth("F       - 持续前进（两个电机同时持续前进）");
  printToBoth("T       - 持续后退（两个电机同时持续后退）");
  printToBoth("TL      - 左转（左电机不转，右侧电机前进）");
  printToBoth("TR      - 右转（右电机不转，左侧电机前进）");
  printToBoth("S       - 停止所有电机");
  printToBoth("SPEED   - 设置电机速度（1-100%）");
  printToBoth("  格式: SPEED<电机><速度> 或 SPEED<电机><速度>,<电机><速度>");
  printToBoth("  示例: SPEEDR50      - 右电机速度设为50%");
  printToBoth("        SPEEDL70,R30  - 左电机70%, 右电机30%");
  printToBoth("        SPEEDB100     - 双电机速度设为100%");
  printToBoth("H       - 显示此帮助信息");
  printToBoth("");
  printToBoth("【速度说明】");
  printToBoth("- 速度值范围: 1-100%");
  printToBoth("- 速度越高，步进延迟越小，电机转得越快");
  printToBoth("- 默认速度: 约33%（300微秒延迟）");
  printToBoth("========================================");
  printToBoth("【注意】");
  printToBoth("使用F或T命令后，电机将持续运行，直到收到S命令停止");
}

// 解析并执行命令
void processCommand(String command) {
  command.trim();  // 去除首尾空格
  
  // 检查命令是否为空
  if (command.length() == 0) {
   // 这是 条件编译指令（仅在编译阶段生效）：
   //若定义了 DEBUG_MODE（通常通过 #define DEBUG_MODE 声明），编译时会保留这条日志打印语句，通过串口输出调试信息，方便开发时排查问题
   //若未定义 DEBUG_MODE（发布版本常用），这条语句会被编译器剔除，不占用运行资源、不输出冗余信息
    #if DEBUG_MODE
    Serial.println("[命令处理] 空命令，忽略");
    #endif
    return;
  }
  
  //command.toUpperCase() 不会是嵌入式底层（如 C 语言）的原生写法，而是 嵌入式上层 / 框架化开发 中的用法 —— 核心仍是 “字符串小写转大写”，但依赖具体的嵌入式语言、RTOS 或框架，而非 C 语言标准库。
  command.toUpperCase(); // 转换为大写
  
  // 命令去重：防止重复命令在短时间内多次执行

  //这行代码是 Arduino（或兼容 AVR/ARM 单片机） 中的常用写法，核心作用是获取系统运行后的 “毫秒级累计时间”，简要解析如下：
  ///1. 变量类型：unsigned long
  //无符号长整型（32 位），取值范围 0 ~ 4294967295（约 49.7 天）；
  //选择该类型是因为：millis() 的返回值本身是 unsigned long，且无符号能避免负数溢出问题（时间只会递增，溢出后从 0 重新计数）。
  //. 函数：millis()
  //核心功能：返回单片机上电（或复位）后累计的 毫秒数（1 秒 = 1000 毫秒）；
  //特性：
  //非阻塞（不暂停程序），底层由定时器中断驱动，程序运行时会自动累计；
  //溢出周期：约 49.7 天（32 位无符号数的最大值 ÷ 1000 毫秒 / 秒 ≈ 49.7 天），溢出后从 0 开始重新计数。
  //3. 整体作用
  //将当前系统累计运行时间（毫秒级）存储到 currentTime 变量中，常用于：
  //计时（如 “延时 N 毫秒后执行某个操作”，替代阻塞的 delay() 函数）；
  //记录事件发生时间（如按键按下、传感器触发的时间戳）；
  //计算时间间隔（如两次操作的时间差）。
  unsigned long currentTime = millis();

  if (command == lastProcessedCommand && 
      (currentTime - lastCommandTime) < COMMAND_DEBOUNCE_MS) {
    #if DEBUG_MODE
    Serial.print("[命令去重] 忽略重复命令: ");
    Serial.print(command);
    Serial.print(" (距上次仅");
    Serial.print(currentTime - lastCommandTime);
    Serial.println("ms)");
    #endif
    return;
  }
  
  // 更新最后处理的命令和时间
  lastProcessedCommand = command;
  lastCommandTime = currentTime;
  
  // 打印接收到的命令
  printToBoth("接收到命令: " + command);
  
  // 帮助命令
  if (command == "H" || command == "HELP") {
    showHelp();
    return;
  }
  
  // 停止命令
  if (command == "S" || command == "STOP") {
    printToBoth("执行停止命令，所有电机停止运动");
    rightMotor.isRunning = false;
    leftMotor.isRunning = false;
    rightMotor.remainingSteps = 0;
    leftMotor.remainingSteps = 0;
    rightMotor.isContinuousRunning = false;
    leftMotor.isContinuousRunning = false;
    return;
  }
  
  // 持续前进命令
  if (command == "F" || command == "FORWARD") {
    printToBoth("执行持续前进命令，两个电机同时前进");
    
    // 设置右电机
    rightMotor.direction = R_FORWARD;
    rightMotor.remainingSteps = 1;  // 设为任意正整数，持续运行模式下不检查
    rightMotor.lastStepTime = micros();
    rightMotor.stepState = LOW;
    rightMotor.isRunning = true;
    rightMotor.isContinuousRunning = true;
    digitalWrite(R_DIR_PIN, rightMotor.direction);
    digitalWrite(R_STEP_PIN, LOW);
    
    // 设置左电机
    leftMotor.direction = L_FORWARD;
    leftMotor.remainingSteps = 1;  // 设为任意正整数，持续运行模式下不检查
    leftMotor.lastStepTime = micros();
    leftMotor.stepState = LOW;
    leftMotor.isRunning = true;
    leftMotor.isContinuousRunning = true;
    digitalWrite(L_DIR_PIN, leftMotor.direction);
    digitalWrite(L_STEP_PIN, LOW);
    
    printToBoth("✓ 两个电机开始持续前进");
    return;
  }
  
  // 持续后退命令
  if (command == "T" || command == "BACKWARD") {
    printToBoth("执行持续后退命令，两个电机同时后退");
    
    // 设置右电机
    rightMotor.direction = R_BACKWARD;
    rightMotor.remainingSteps = 1;  // 设为任意正整数，持续运行模式下不检查
    rightMotor.lastStepTime = micros();
    rightMotor.stepState = LOW;
    rightMotor.isRunning = true;
    rightMotor.isContinuousRunning = true;
    digitalWrite(R_DIR_PIN, rightMotor.direction);
    digitalWrite(R_STEP_PIN, LOW);
    
    // 设置左电机
    leftMotor.direction = L_BACKWARD;
    leftMotor.remainingSteps = 1;  // 设为任意正整数，持续运行模式下不检查
    leftMotor.lastStepTime = micros();
    leftMotor.stepState = LOW;
    leftMotor.isRunning = true;
    leftMotor.isContinuousRunning = true;
    digitalWrite(L_DIR_PIN, leftMotor.direction);
    digitalWrite(L_STEP_PIN, LOW);
    
    printToBoth("✓ 两个电机开始持续后退");
    return;
  }
  
  // 左转命令（左电机不转，右侧电机前进）
  if (command == "TL" || command == "TURNLEFT") {
    printToBoth("执行左转命令，左电机不转，右侧电机前进");
    
    // 设置右电机前进
    rightMotor.direction = R_FORWARD;
    rightMotor.remainingSteps = 1;  // 设为任意正整数，持续运行模式下不检查
    rightMotor.lastStepTime = micros();
    rightMotor.stepState = LOW;
    rightMotor.isRunning = true;
    rightMotor.isContinuousRunning = true;
    digitalWrite(R_DIR_PIN, rightMotor.direction);
    digitalWrite(R_STEP_PIN, LOW);
    
    // 确保左电机停止
    leftMotor.isRunning = false;
    leftMotor.remainingSteps = 0;
    leftMotor.isContinuousRunning = false;
    
    printToBoth("✓ 已执行左转命令");
    return;
  }
  
  // 右转命令（右电机不转，左侧电机前进）
  if (command == "TR" || command == "TURNRIGHT") {
    printToBoth("执行右转命令，右电机不转，左侧电机前进");
    
    // 设置左电机前进
    leftMotor.direction = L_FORWARD;
    leftMotor.remainingSteps = 1;  // 设为任意正整数，持续运行模式下不检查
    leftMotor.lastStepTime = micros();
    leftMotor.stepState = LOW;
    leftMotor.isRunning = true;
    leftMotor.isContinuousRunning = true;
    digitalWrite(L_DIR_PIN, leftMotor.direction);
    digitalWrite(L_STEP_PIN, LOW);
    
    // 确保右电机停止
    rightMotor.isRunning = false;
    rightMotor.remainingSteps = 0;
    rightMotor.isContinuousRunning = false;
    
    printToBoth("✓ 已执行右转命令");
    return;
  }
  
  // BOTH命令 - 独立控制两个电机
  if (command.startsWith("BOTH")) {
  
  int commaPos = command.indexOf(',');
    
    if (commaPos <= 4) {
      printToBoth("命令格式错误！");
      printToBoth("格式: BOTH<右方向><右步数>,<左方向><左步数>");
      printToBoth("例如: BOTHF500,B1000");
      return;
    }
    
    // 解析右电机参数
    String rightPart = command.substring(4, commaPos);
    if (rightPart.length() < 2) {
      printToBoth("右电机参数格式错误");
      return;
    }
   // 获取字符串中指定索引位置的字符：
   //索引从 0 开始（字符串的第一个字符对应索引 0，第二个对应 1，以此类推）；
   //charAt(0) 即明确获取 “字符串的第一个字符”
    char rightDir = rightPart.charAt(0);
    int rightSteps = rightPart.substring(1).toInt();
    
    // 解析左电机参数
    String leftPart = command.substring(commaPos + 1);
    if (leftPart.length() < 2) {
      printToBoth("左电机参数格式错误");
      return;
    }
    char leftDir = leftPart.charAt(0);
    int leftSteps = leftPart.substring(1).toInt();
    
    // 验证参数
    if ((rightDir != 'F' && rightDir != 'B') || (leftDir != 'F' && leftDir != 'B')) {
      printToBoth("方向标识错误，应为F(正转)或B(反转)");
      return;
    }
    
    if (rightSteps <= 0 || leftSteps <= 0) {
      printToBoth("步数必须为正整数");
      return;
    }
    
    // 显示控制信息
    String rightDirStr = (rightDir == 'F') ? "正转" : "反转";
    String leftDirStr = (leftDir == 'F') ? "正转" : "反转";
    printToBoth("右电机" + rightDirStr + String(rightSteps) + "步, 左电机" + leftDirStr + String(leftSteps) + "步");
    
    // 设置右电机
    rightMotor.direction = (rightDir == 'F') ? R_FORWARD : R_BACKWARD;
    rightMotor.remainingSteps = rightSteps;
    rightMotor.lastStepTime = micros();
    rightMotor.stepState = LOW;  // 初始化为LOW状态
    rightMotor.isRunning = true;
    digitalWrite(R_DIR_PIN, rightMotor.direction);
    digitalWrite(R_STEP_PIN, LOW);  // 确保初始为LOW
    
    // 设置左电机
    leftMotor.direction = (leftDir == 'F') ? L_FORWARD : L_BACKWARD;
    leftMotor.remainingSteps = leftSteps;
    leftMotor.lastStepTime = micros();
    leftMotor.stepState = LOW;  // 初始化为LOW状态
    leftMotor.isRunning = true;
    digitalWrite(L_DIR_PIN, leftMotor.direction);
    digitalWrite(L_STEP_PIN, LOW);  // 确保初始为LOW
    
    printToBoth("✓ 两个电机已开始独立运行");
    return;
  }
  
  // 单个电机控制
  if (command.length() >= 3) {
    //charAt(0)：字符串的内置方法，作用是获取字符串中指定索引位置的字符。索引从 0 开始（第一个字符索引为 0，第二个为 1，以此类推），所以 charAt(0) 就是取字符串的 “第一个字符”；
    char motor = command.charAt(0);
    char direction = command.charAt(1);
    
    if ((motor == 'R' || motor == 'L') && (direction == 'F' || direction == 'B')) {
      String stepsStr = command.substring(2);
      int steps = stepsStr.toInt();
      
      if (steps <= 0) {
        printToBoth("步数必须为正整数");
        return;
      }
      
      if (motor == 'R') {
        String msg = "右电机" + String(direction == 'F' ? "正转" : "反转") + String(steps) + "步";
        printToBoth(msg);
        
        rightMotor.direction = (direction == 'F') ? R_FORWARD : R_BACKWARD;
        rightMotor.remainingSteps = steps;
        rightMotor.lastStepTime = micros();
        rightMotor.stepState = LOW;
        rightMotor.isRunning = true;
        digitalWrite(R_DIR_PIN, rightMotor.direction);
        digitalWrite(R_STEP_PIN, LOW);
        
      } else if (motor == 'L') {
        String msg = "左电机" + String(direction == 'F' ? "正转" : "反转") + String(steps) + "步";
        printToBoth(msg);
        
        leftMotor.direction = (direction == 'F') ? L_FORWARD : L_BACKWARD;
        leftMotor.remainingSteps = steps;
        leftMotor.lastStepTime = micros();
        leftMotor.stepState = LOW;
        leftMotor.isRunning = true;
        digitalWrite(L_DIR_PIN, leftMotor.direction);
        digitalWrite(L_STEP_PIN, LOW);
      }
      
      printToBoth("✓ 命令已设置");
      return;
    }
  }
  
  // 速度控制命令
  if (command.startsWith("SPEED")) {
    // 解析速度命令：SPEED<电机><速度> 或 SPEED<电机><速度>,<电机><速度>
    String speedCommand = command.substring(5); // 去掉"SPEED"
    
    // 检查是否有逗号分隔的多个参数
    int commaPos = speedCommand.indexOf(',');
    
    if (commaPos > 0) {
      // 多个速度参数
      String firstPart = speedCommand.substring(0, commaPos);
      String secondPart = speedCommand.substring(commaPos + 1);
      
      // 处理第一个参数
      if (firstPart.length() >= 2) {
        char motor1 = firstPart.charAt(0);
        int speed1 = firstPart.substring(1).toInt();
        processSpeedCommand(motor1, speed1);
      }
      
      // 处理第二个参数
      if (secondPart.length() >= 2) {
        char motor2 = secondPart.charAt(0);
        int speed2 = secondPart.substring(1).toInt();
        processSpeedCommand(motor2, speed2);
      }
    } else {
      // 单个速度参数
      if (speedCommand.length() >= 2) {
        char motor = speedCommand.charAt(0);
        int speed = speedCommand.substring(1).toInt();
        processSpeedCommand(motor, speed);
      }
    }
    
    return;
  }
  
  // 未知命令
  printToBoth("未知命令，输入 H 查看帮助信息");
}
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
void loop() {
  // 检查串口或蓝牙是否有数据到达
  while (availableData() > 0) {
    char incomingByte = readByte();
    
    #if DEBUG_MODE
    // 调试：显示接收到的每个字符
    if (incomingByte == '\n') {
      Serial.println("[接收字符] \\n (换行)");
    } else if (incomingByte == '\r') {
      Serial.println("[接收字符] \\r (回车)");
    } else if (incomingByte >= 32 && incomingByte <= 126) {
      Serial.print("[接收字符] '");
      Serial.print(incomingByte);
      Serial.println("'");
    } else {
      Serial.print("[接收字符] 0x");
      Serial.println((byte)incomingByte, HEX);
    }
    #endif
    
    // 如果收到换行符或回车符，处理完整命令
    if (incomingByte == '\n' || incomingByte == '\r') {
      if (receivedCommand.length() > 0) {
        #if DEBUG_MODE
        Serial.print("[处理命令] 长度:");
        Serial.print(receivedCommand.length());
        Serial.print(" 内容:'");
        Serial.print(receivedCommand);
        Serial.println("'");
        #endif
        
        processCommand(receivedCommand);
        receivedCommand = "";
      }
    } else {
      // 过滤掉不可见的控制字符（除了换行回车）
      if (incomingByte >= 32 && incomingByte <= 126) {
        receivedCommand += incomingByte;
      } else {
        #if DEBUG_MODE
        Serial.print("[忽略字符] 0x");
        Serial.println((byte)incomingByte, HEX);
        #endif
      }
    }
  }
  
  // 更新两个电机的状态 - 非阻塞方式
  updateMotor(rightMotor);
  updateMotor(leftMotor);
  
  // BLE断开重连处理

  /*左侧 !deviceConnected：deviceConnected 表示「当前设备是否连接」
  （布尔值：true = 连接，false = 未连接），! 是逻辑非，所以整体意思是「当前设备未连接」。
  右侧 oldDeviceConnected：oldDeviceConnected 表示「上一次状态中设备是否连接」，
  整体意思是「上一次设备是连接的」。
  逻辑与（&&）：只有左右两侧同时为 true 时，整个表达式才返回 true。*/
  if (!deviceConnected && oldDeviceConnected) {
    delay(500);

    /* BLEServer：可以理解为"蓝牙服务器"的功能说明书，它定义了ESP32如何作为蓝牙服务器工作的所有规则和能力。 *：
    星号表示这是一个指针变量（可以理解为"地址簿"，用来存储某个"东西"的位置）。 pServer：这是给这个变量起的名字
    （类似地址簿的名称，比如"我家的地址簿"）。 = NULL：
    把这个地址簿初始化为空（表示这个地址簿里还没有写任何地址）*/
    pServer->startAdvertising();
    #if DEBUG_MODE
    Serial.println("开始广播，等待重连...");
    #endif
    oldDeviceConnected = deviceConnected;
  }
  
  // BLE连接成功处理
  if (deviceConnected && !oldDeviceConnected) {
    oldDeviceConnected = deviceConnected;
    printToBoth("ESP32S3 双步进电机独立控制系统");
    printToBoth("输入 H 查看帮助信息");
  }
}

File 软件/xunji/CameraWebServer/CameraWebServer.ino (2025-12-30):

//======================================================================
// PART 1: CameraWebServer.ino 原始代码的顶部和库引用
//======================================================================

#include "esp_camera.h"
#include <WiFi.h>

// ---------------------------------------------------------------------
// 【新增】BLE 和 FreeRTOS 库引用
// ---------------------------------------------------------------------
#include <BLEDevice.h>
#include <BLEServer.h>
#include <BLEUtils.h>
#include <BLE2902.h>
#include "freertos/FreeRTOS.h"
#include "freertos/task.h"
#include "freertos/queue.h"

// ===========================
// Select camera model in board_config.h
// ===========================
#include "board_config.h"

// ===========================
// Enter your WiFi credentials
// ===========================
const char *ssid = "具身智能机器人-2.4G";
const char *password = "jushen123";

void startCameraServer();
void setupLedFlash();

//======================================================================
// PART 2: 【新增】BLE 变量、电机引脚、FreeRTOS 结构体和函数定义
//======================================================================

// ---------------------------------------------------------------------
// 1. BLE 服务使用 Nordic UART Profile 
// ---------------------------------------------------------------------
#define SERVICE_UUID       "6E400001-B5A3-F393-E0A9-E50E24DCCA9E"
#define RX_CHARACTERISTIC_UUID "6E400002-B5A3-F393-E0A9-E50E24DCCA9E"
#define TX_CHARACTERISTIC_UUID "6E400003-B5A3-F393-E0A9-E50E24DCCA9E"

BLECharacteristic* pTxCharacteristic = nullptr; // 用来向 Python 发送数据的特征（通知用）
bool deviceConnected = false;          // 当前是否有手机/电脑通过蓝牙连上了


// ---------------------------------------------------------------------
// 2. 电机引脚定义（已修正为安全引脚）
// ---------------------------------------------------------------------
// 右电机引脚
#define R_STEP_PIN   1 // 右电机脉冲信号 
#define R_DIR_PIN   2 // 右电机方向信号
#define R_ENABLE_PIN  3 // 右电机使能信号

// 左电机引脚
#define L_STEP_PIN  14  // 左电机脉冲信号
#define L_DIR_PIN   15  // 左电机方向信号
#define L_ENABLE_PIN 16  // 左电机使能信号


// ---------------------------------------------------------------------
// 3. FreeRTOS 任务间通信结构体 (用于传递指令)
// ---------------------------------------------------------------------
typedef enum {
  CMD_RP1,    // 右电机 正向一步
  CMD_RP0,    // 右电机 反向一步
  CMD_LP1,    // 左电机 正向一步
  CMD_LP0,    // 左电机 反向一步
  CMD_ENABLE_ON, // 使能开启
  CMD_ENABLE_OFF // 使能关闭
} MotorCommand_t;

// 队列句柄，用于在 BLE 和 Motor Task 之间安全传递指令
QueueHandle_t motorCommandQueue; 

// ---------------------------------------------------------------------
// 4. 电机使能控制函数
// ---------------------------------------------------------------------
void enableMotors() {
 digitalWrite(R_ENABLE_PIN, LOW);  // 低电平 = 使能
 digitalWrite(L_ENABLE_PIN, LOW);
 Serial.println("电机已使能（有力矩）");
}

void disableMotors() {
 digitalWrite(R_ENABLE_PIN, HIGH); // 高电平 = 关闭使能
 digitalWrite(L_ENABLE_PIN, HIGH);
 Serial.println("电机已关闭使能（急停/省电/可手推）");
}


// ---------------------------------------------------------------------
// 5. 【重构】电机脉冲逻辑（由 Motor Task 调用）
// ---------------------------------------------------------------------
void executePulse(int stepPin, int dirPin, int enablePin, bool forward) {
 // 必须先使能，否则没力
 digitalWrite(enablePin, LOW); 
 // 设置方向
 digitalWrite(dirPin, forward ? HIGH : LOW);
 // 脉冲序列
 digitalWrite(stepPin, HIGH);     
 ets_delay_us(5); // 使用ets_delay_us替代delayMicroseconds，减少调度器干预
 digitalWrite(stepPin, LOW);
}


// ---------------------------------------------------------------------
// 6. 【核心】Motor Task - FreeRTOS 任务函数 (已修复队列接收参数)
// ---------------------------------------------------------------------
void motor_task(void *pvParameters) {
  MotorCommand_t currentCmd;

  Serial.println("Motor Task: 任务已启动，等待 BLE 指令...");

  // 任务的无限循环
  while (1) {
    // 尝试从队列中读取指令，等待时间设置为 100 毫秒
    // 之前使用 portMAX_DELAY 导致了断言错误，现在使用有限等待
    if (xQueueReceive(motorCommandQueue, &currentCmd, pdMS_TO_TICKS(100)) == pdTRUE) { 
      // 收到指令，开始执行
      switch (currentCmd) {
        case CMD_RP1:
          Serial.println("Motor Task: 执行 RP1 (右正)");
          executePulse(R_STEP_PIN, R_DIR_PIN, R_ENABLE_PIN, true);
          break;
        case CMD_RP0:
          Serial.println("Motor Task: 执行 RP0 (右反)");
          executePulse(R_STEP_PIN, R_DIR_PIN, R_ENABLE_PIN, false);
          break;
        case CMD_LP1:
          Serial.println("Motor Task: 执行 LP1 (左正)");
          executePulse(L_STEP_PIN, L_DIR_PIN, L_ENABLE_PIN, true);
          break;
        case CMD_LP0:
          Serial.println("Motor Task: 执行 LP0 (左反)");
          executePulse(L_STEP_PIN, L_DIR_PIN, L_ENABLE_PIN, false);
          break;
        case CMD_ENABLE_ON:
          enableMotors();
          break;
        case CMD_ENABLE_OFF:
          disableMotors();
          break;
        default:
          break;
      }
    }
    // 不需要额外的延迟，xQueueReceive已经会让出CPU时间
  }
}


// ---------------------------------------------------------------------
// 7. BLE 接收回调（将指令发送到队列，不再阻塞）
// ---------------------------------------------------------------------
class MyCallbacks : public BLECharacteristicCallbacks {
 void onWrite(BLECharacteristic* pChar) {
  auto val = pChar->getValue();
  String cmd = String(val.c_str());
  cmd.trim();
  if (cmd.length() == 0) return;
  cmd.toUpperCase();

  Serial.print("BLE 收到指令 → ");
  Serial.println(cmd);
   
  // 回显到客户端（如果已连接）
  if (deviceConnected) {
   pTxCharacteristic->setValue(cmd);
   pTxCharacteristic->notify();
  }

  MotorCommand_t commandToSend;
  bool sendToQueue = true;

  // 指令解析
  if (cmd == "RP1")   commandToSend = CMD_RP1;
  else if (cmd == "RP0") commandToSend = CMD_RP0;
  else if (cmd == "LP1") commandToSend = CMD_LP1;
  else if (cmd == "LP0") commandToSend = CMD_LP0;
  else if (cmd == "ENABLE_ON") commandToSend = CMD_ENABLE_ON;
  else if (cmd == "ENABLE_OFF" || cmd == "STOP" || cmd == "ESTOP") {
   commandToSend = CMD_ENABLE_OFF; 
   Serial.println("紧急停止触发！");
  }
  else if (cmd == "TEST" || cmd == "PING") {
   Serial.println("PONG → 设备正常运行");
   sendToQueue = false; // 不需要发送到电机队列
  } else {
   sendToQueue = false; // 未知指令
  }

  // 将指令发送到电机任务队列（异步操作，不阻塞）
  if (sendToQueue) {
   if (xQueueSend(motorCommandQueue, &commandToSend, 0) != pdPASS) {
    Serial.println("警告: 队列已满，指令丢失。");
   }
  }
 }
};

// ---------------------------------------------------------------------
// BLE 连接/断开回调（用于断线重连）
// ---------------------------------------------------------------------
class ServerCallbacks : public BLEServerCallbacks {
 void onConnect(BLEServer* pServer) {
  deviceConnected = true;
  Serial.println("Client Connected.");
 }
 void onDisconnect(BLEServer* pServer) {
  deviceConnected = false;
  Serial.println("Client Disconnected.");
 }
};


//======================================================================
// PART 3: CameraWebServer.ino 原始 setup() 函数的修改和整合
//======================================================================
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
